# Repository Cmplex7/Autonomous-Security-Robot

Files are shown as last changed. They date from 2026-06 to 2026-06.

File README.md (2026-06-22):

# Autonomous Security Robot Platform

Autonomous security robot with real-time SLAM mapping, web dashboard control, interactive expressions, and obstacle avoidance.
Built on Raspberry Pi 4 + ROS2 Humble + STM32F103 + ESP32.

## Project Overview

* Motor Controller: STM32F103C8T6 (Blue Pill)
* Main Computer: Raspberry Pi 4 Model B (4GB) running Ubuntu Server 22.04 LTS + ROS2 Humble
* Interactive Display: ESP32 driving 2x GC9A01 Round LCDs (Robot Eyes)
* LiDAR: RPLidar A1M8 (sllidar_ros2 + slam_toolbox)
* IMU: MPU6050 GY-521
* Camera: IMX219 (Raspberry Pi Camera v2)
* Web Dashboard: rosbridge + vanilla JS

## System Architecture
```text
┌─────────────────────────────────────────────────────┐
│                Raspberry Pi 4                       │
│  ┌──────────┐  ┌──────────┐  ┌──────────────────┐   │
│  │  slam_   │  │rosbridge │  │   cam_stream.py  │   │
│  │ toolbox  │  │  :9090   │  │   (MJPEG :8080)  │   │
│  └────┬─────┘  └────┬─────┘  └──────────────────┘   │
│       │ /map        │ WebSocket                     │
│  ┌────┴──────────────────────────────────────┐      │
│  │         ROS2 Humble (CycloneDDS)          │      │
│  │  /scan_filtered  /imu/data  /cmd_vel      │      │
│  └──┬─────────────┬──────────────────────────┘      │
│     │             │                                 │
│  ┌──┴──────┐  ┌───┴─────────┐                       │
│  │RPLidar  │  │  MPU6050    │  uart_bridge.py       │
│  │ A1M8    │  │  GY-521     │  GPIO UART -> STM32   │
│  └─────────┘  └─────────────┘                       │
└─────────────────────────────────────────────────────┘
            ↕ WebSocket ws://pi-ip:9090
┌─────────────────────────────────────────────────────┐
│               Web Browser (any device)              │
│  ┌────────────────────────────────────────────────┐ │
│  │  SLAM Map · Camera Feed · Joystick · D-pad     │ │
│  │          web/index.html (served by Pi)         │ │
│  └────────────────────────────────────────────────┘ │
└─────────────────────────────────────────────────────┘
            ↕ UART (115200 baud, GPIO14/15)
┌─────────────────────────────────────────────────────┐
│                STM32F103C8T6                        │
│  Motor PWM · HC-SR04 Ultrasonic · AUTO navigation   │
└─────────────────────────────────────────────────────┘
┌─────────────────────────────────────────────────────┐
│                ESP32 (Expression Module)            │
│  SPI Bus -> 2x GC9A01 Round LCDs (Interactive Eyes) │
└─────────────────────────────────────────────────────┘
```
## Repository Structure

* /docs: Setup guides, wiring diagrams, and motor shield datasheets.
* /hardware: 3D printed mechanical parts and KiCAD PCB schematics.
* /stm32: Low-level STM32 firmware for motor control and obstacle avoidance.
* /esp32: Firmware for LCD eyes rendering and animation control.
* /raspberry_pi: ROS2 workspace containing custom nodes for IMU processing and UART bridging.
* /web: Web dashboard interface and MJPEG camera streaming script.

## Hardware Integration & Wiring

ESP32 to GC9A01 Round LCDs (SPI)
* MOSI / SCLK: Shared SPI data and clock lines for both screens.
* CS1 / CS2: Independent Chip Select pins to control Left and Right eyes.
* DC / RST: Data/Command and Reset pins.

STM32 to Motor Driver (L298N / TB6612)
* PA0 (ENA) / PA1 (ENB): Motor PWM
* PA2 / PA3: Left motor direction
* PA4 / PA5: Right motor direction

Pi 4 to STM32 (UART)
* GPIO14 (TX, pin 8) -> RX (PA10 / Serial1)
* GPIO15 (RX, pin 10) -> TX (PA9 / Serial1)

Please refer to the /docs directory for complete wiring diagrams and system setup instructions.

## Quick Start

1. Clone the repository:
   git clone https://github.com/Cmplex7/Autonomous-Security-Robot.git

2. Flash STM32 Firmware: Open `stm32/robot_final.ino` in Arduino IDE with the STM32duino board package. Upload via Serial or ST-Link at 115200 baud.

3. Flash ESP32 Firmware: Upload the GC9A01 display code to the ESP32 module to initialize the screen animations.

4. Set Up Raspberry Pi 4: Follow the detailed setup guide in the `docs/` folder to install Ubuntu Server 22.04 LTS and ROS2 Humble.

5. Launch Workspace: Compile the ROS2 packages using `colcon build` and launch the bringup scripts.

## STM32 UART Command Protocol

Commands are sent as ASCII strings terminated with \n at 115200 baud:
* ON / BACK / LEFT / RIGHT: Basic directional movement
* UP_LEFT / UP_RIGHT / DOWN_LEFT / DOWN_RIGHT: Arced movement
* AUTO: Enable onboard ultrasonic obstacle avoidance
* OFF / MANUAL: Stop and exit AUTO mode

## Author
ThanhDat (CmpleX7)

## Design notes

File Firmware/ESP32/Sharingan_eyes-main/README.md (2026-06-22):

# Sharingan Eyes 👁️👁️

Mắt hoạt hình (animated eyes) trên ESP32 với **lõi mắt thay được lúc chạy** bằng nút bấm:
mắt người → Sharingan tomoe → Mangekyou Kamui (Obito) → Mangekyou vĩnh hằng (Sasuke) → Rinnegan.

Mắt tự đảo tròng, chớp mắt, mí mắt bám theo con ngươi — dựa trên engine
"Uncanny Eyes" của Adafruit, bản port TFT_eSPI cho ESP32.

## Phần cứng

- ESP32 DevKit V1 (loại thông dụng, chip CH340)
- 2 × LCD tròn 1.28" GC9A01, 240×240 (chân BLK, CS, DC, RES, SDA, SCL, VCC, GND)
- 1 nút bấm (đổi lõi mắt)

### Sơ đồ đấu dây

| Chân màn hình | Màn TRÁI | Màn PHẢI | Ghi chú |
|---|---|---|---|
| VCC | 3V3 | 3V3 | ⚠️ Không cắm 5V, không đảo ngược VCC/GND |
| GND | GND | GND | |
| SCL | GPIO 18 | GPIO 18 | SPI clock, dùng chung |
| SDA | GPIO 23 | GPIO 23 | SPI MOSI, dùng chung |
| DC | GPIO 22 | GPIO 22 | Dùng chung |
| RES | GPIO 4 | GPIO 4 | Dùng chung |
| CS | GPIO 5 | GPIO 21 | Mỗi màn một chân riêng |
| BLK | 3V3 | 3V3 | Đèn nền luôn bật |

Nút bấm: một chân **GPIO 27**, chân kia **GND** (dùng pull-up nội, không cần điện trở).

## Build & nạp (PlatformIO)

```bash
pio run -t upload
```

Cổng COM và toàn bộ cấu hình chân TFT_eSPI nằm trong `platformio.ini` (build_flags),
không cần sửa `User_Setup.h` của thư viện. Cấu hình mắt trong `include/config.h`.

## Đổi lõi mắt

Nhấn nút GPIO27: xoay vòng qua 5 lõi. Mỗi lần đổi, firmware in `Doi loi mat -> ...`
ra Serial (115200). Lõi khởi động mặc định đặt trong `main.cpp` (`irisStyleIndex`).

## Tự tạo lõi mắt mới

Engine không nhận ảnh tròn trực tiếp — iris là texture 256×64 "trải" theo tọa độ cực
(cột = góc 0–360°, hàng = bán kính từ mép vào tâm). Dùng script kèm theo:

```bash
python tools/make_iris.py anh_tron.png iris_ten_moi iris_ten_moi.h [cx cy r]
```

Script xuất kèm ảnh `_preview.png` (tái dựng hình tròn) để soát trước khi nạp.
Sau đó: copy file `.h` vào `src/eyes/`, thêm `#include` trong `include/config.h`,
và thêm một dòng vào bảng `irisStyles[]` trong `src/main.cpp` với scale `121, 121`.

> **Lưu ý kỹ thuật:** lõi "phẳng" (texture phủ kín cả vòng iris) phải dùng
> `iScale = 121`, không phải 120. Pixel ngoài vòng tròn iris mang mã polar
> `dist = 127`; cần `121×127/240 = 64 ≥ IRIS_MAP_HEIGHT` để chúng rơi ra lòng
> trắng — với 120 chúng rơi vào hàng 63 của texture và iris sẽ bị **vuông**.
> Lõi mắt người mặc định dùng `IRIS_MIN/IRIS_MAX` (180–280) nên có hiệu ứng
> giãn/co đồng tử; lõi Sharingan cố định đồng tử.

Preview các lõi có sẵn (sinh bởi `make_iris.py`):

| Tomoe | Kamui | Sasuke | Rinnegan |
|---|---|---|---|
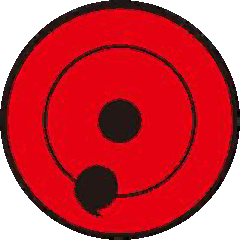
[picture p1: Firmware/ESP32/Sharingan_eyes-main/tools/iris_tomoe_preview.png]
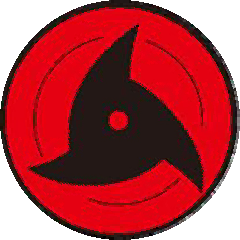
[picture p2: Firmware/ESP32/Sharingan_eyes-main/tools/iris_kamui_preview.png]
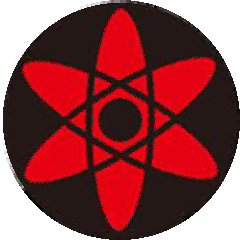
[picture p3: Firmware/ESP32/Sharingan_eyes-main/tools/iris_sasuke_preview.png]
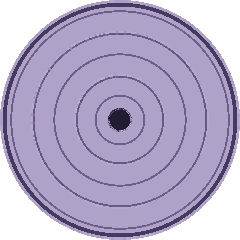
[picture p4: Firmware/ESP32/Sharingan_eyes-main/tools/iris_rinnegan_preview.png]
|  |  |  |  |

## Ghi công

- Engine gốc: [Uncanny Eyes](https://github.com/adafruit/Uncanny_Eyes) — Phil Burgess / Adafruit
- Port TFT_eSPI + ESP32: dự án ESP32-UncannyEyes (PlatformIO, xem `readme_goc.md`) và các ví dụ Animated Eyes của [Bodmer/TFT_eSPI](https://github.com/Bodmer/TFT_eSPI)
- Lõi Sharingan/Rinnegan + nút đổi lõi lúc chạy + script `make_iris.py`: repo này

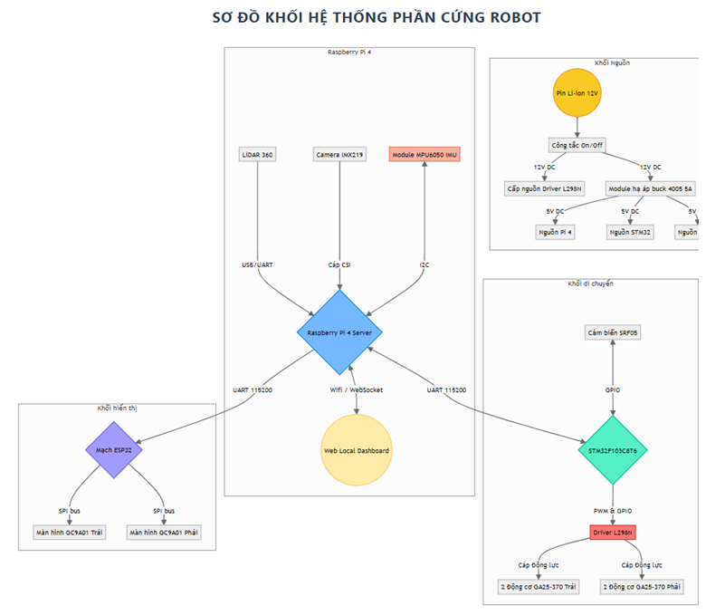
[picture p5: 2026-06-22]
Docs/Robot_System_Diagram.png

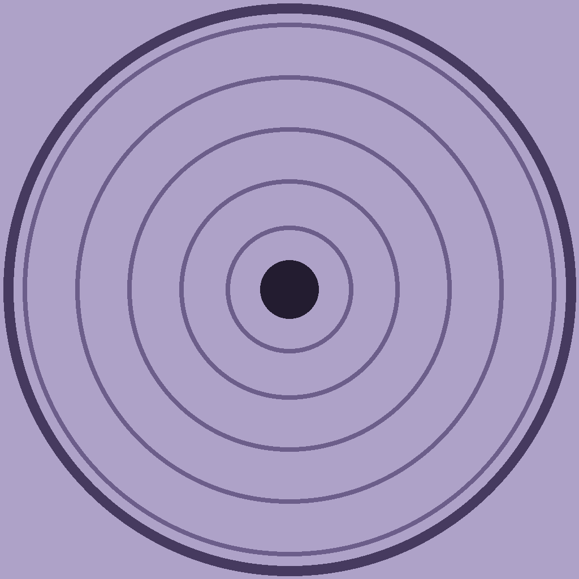
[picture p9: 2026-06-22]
Firmware/ESP32/Sharingan_eyes-main/tools/rinnegan_src.png

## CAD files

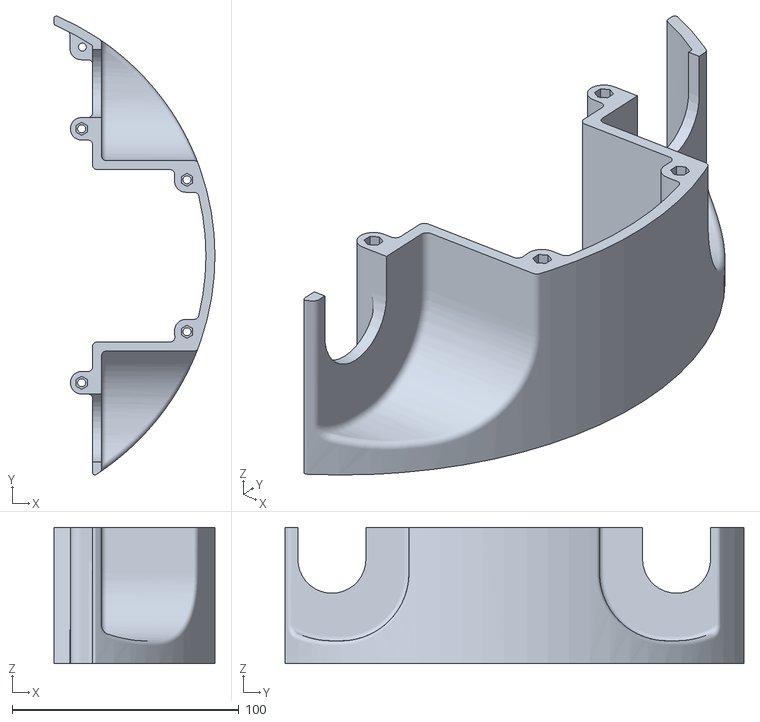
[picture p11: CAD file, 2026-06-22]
System Design/Security Robot Design/tấm 1.STL
71.0 x 202.4 x 60.0

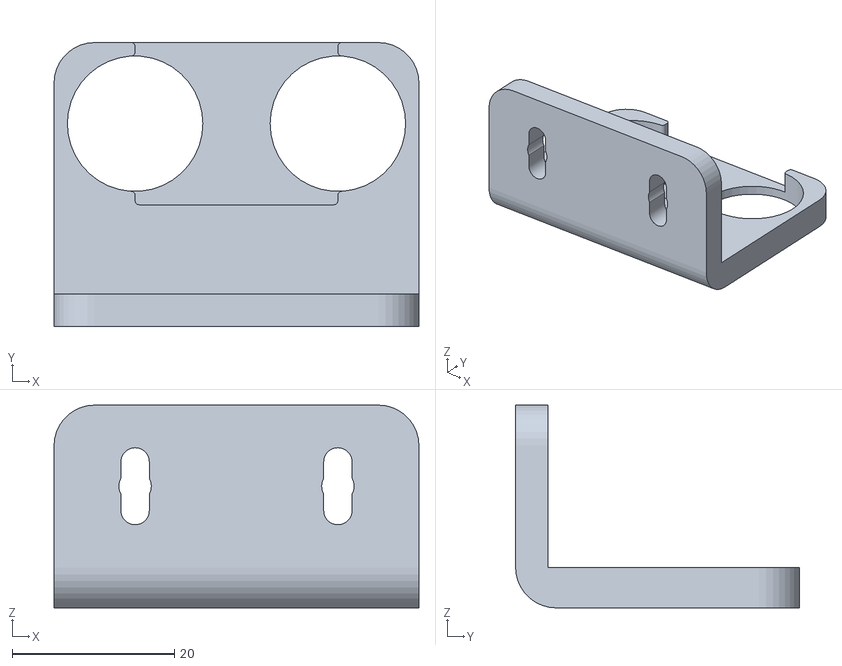
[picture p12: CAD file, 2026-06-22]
System Design/Security Robot Design/4x kẹp cảm biến siêu âm.STL
45.0 x 35.0 x 25.0

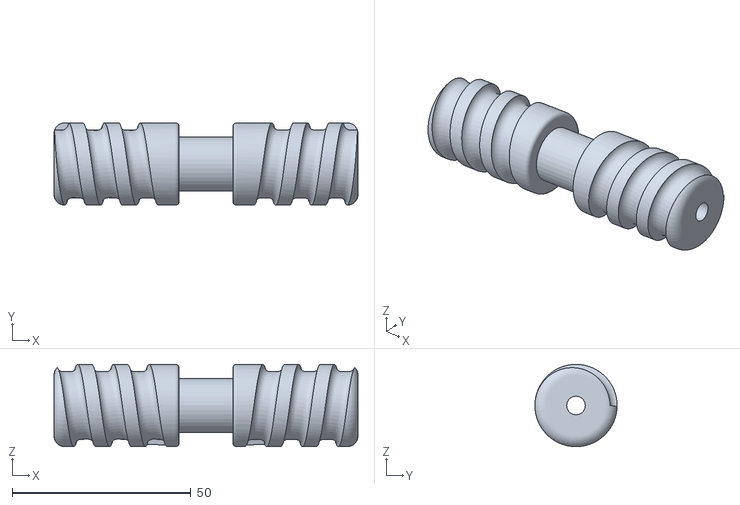
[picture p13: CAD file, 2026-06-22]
System Design/Security Robot Design/1x con lăn định tâm.STL
85.0 x 23.0 x 23.0

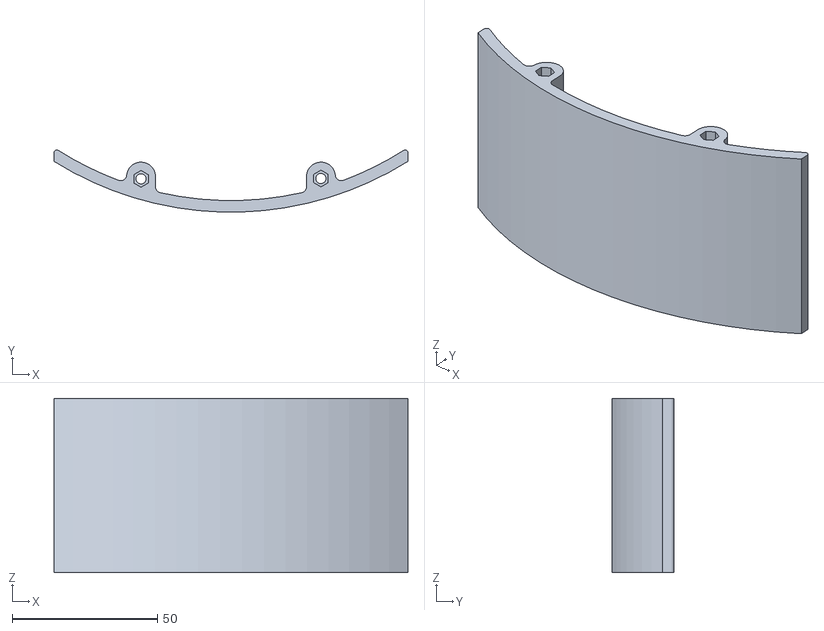
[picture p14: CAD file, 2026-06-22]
System Design/Security Robot Design/tấm 3.STL
122.0 x 21.4 x 60.0

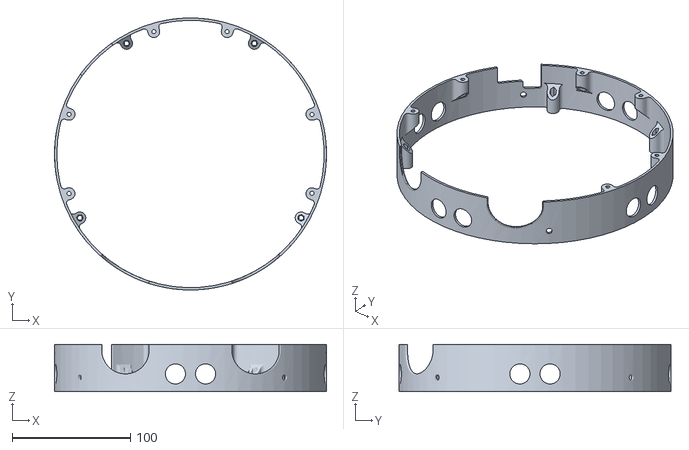
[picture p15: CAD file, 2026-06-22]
System Design/Security Robot Design/1x tang 2.STL
230.0 x 229.8 x 40.0

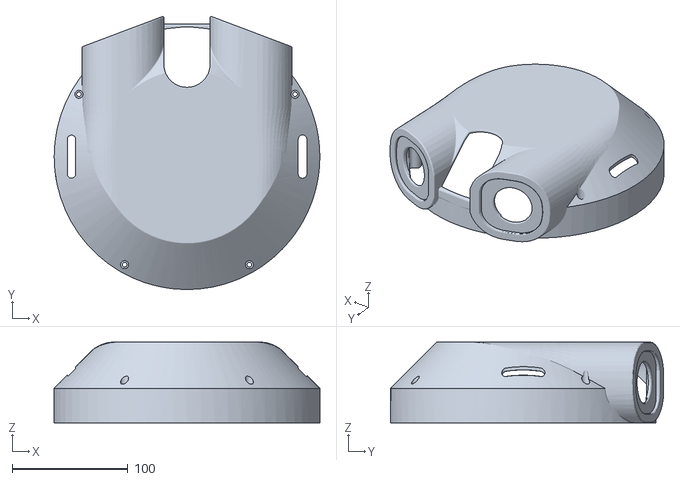
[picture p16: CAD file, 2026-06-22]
System Design/Security Robot Design/1x tang 3.STL
230.0 x 236.3 x 70.0

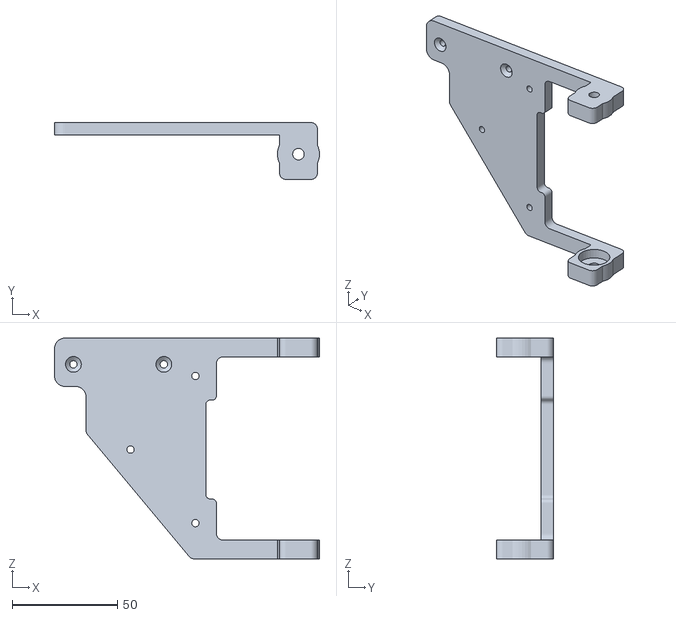
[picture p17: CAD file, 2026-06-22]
System Design/Security Robot Design/1x đỡ định tâm bóng.STL
126.0 x 27.0 x 105.0

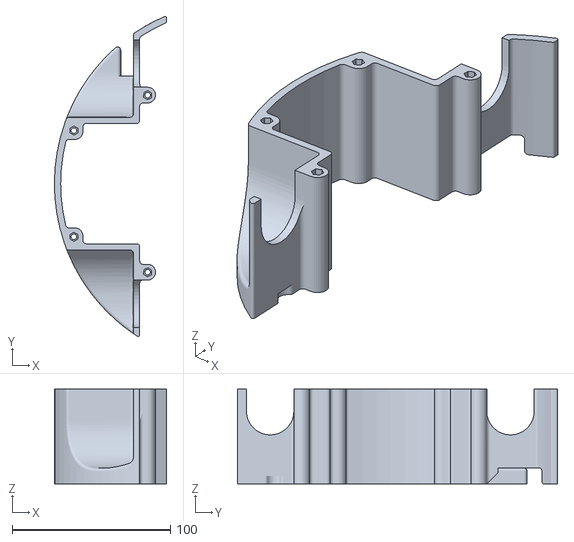
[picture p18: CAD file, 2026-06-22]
System Design/Security Robot Design/1x tấm 2.STL
71.0 x 202.4 x 60.0

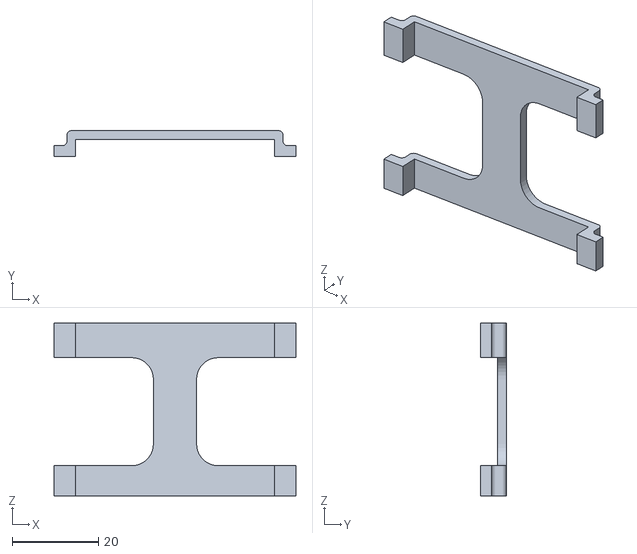
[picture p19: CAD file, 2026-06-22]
System Design/Security Robot Design/2x nẹp.STL
56.0 x 5.96 x 40.0

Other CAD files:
System Design/Security Robot Design/01_mica.DXF
System Design/Security Robot Design/00_mica.DXF
System Design/Security Robot Design/02_mica.DXF

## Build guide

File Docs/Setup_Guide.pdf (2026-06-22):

# Cài trên Pi

## 1.1. Pi4 model B + RPLidar A1M8 - Cài đặt Ubuntu Server 22 LTS (64-bit) + Hostname: robotanninh + Username/ Password: ubuntu/ abc123 + Kết nối Lidar và Pi4b qua USB - USB micro B, cổng đen

## - Cập nhật hệ điều hành:

sudo apt update && sudo apt upgrade -y sudo reboot

## - Tạo file swap 4GB ram ảo:

sudo fallocate -l 4G /swapfile
sudo chmod 600 /swapfile
sudo mkswap /swapfile
sudo swapon /swapfile
echo '/swapfile none swap sw 0 0' | sudo tee -a /etc/fstab

## - Thiết lập ngôn ngữ:

sudo apt install -y software-properties-common curl locales
sudo locale-gen en_US en_US.UTF-8
sudo update-locale LC_ALL=en_US.UTF-8 LANG=en_US.UTF-8 export LANG=en_US.UTF-8

## - Kích hoạt kho Universe:

sudo add-apt-repository universe -y

## 1.2. Thêm ROS2 Humble repository:

sudo apt install -y curl
export ROS_APT_SOURCE_VERSION=$(curl -s \ https://api.github.com/repos/ros-infrastructure/ros-apt-source/releases/latest \
| grep -F '"tag_name"' | awk -F\" '{print $4}')
echo "ros-apt-source version: $ROS_APT_SOURCE_VERSION"

curl -L -o /tmp/ros2-apt-source.deb \

"https://github.com/ros-infrastructure/ros-apt-source/releases/download/${ROS_APT_SOURCE_VERSION}/ros2-apt-source_${ROS_APT_SOURCE_VERSION}.$(. /etc/os-release && echo $VERSION_CODENAME)_all.deb"
sudo dpkg -i /tmp/ros2-apt-source.deb

## - Cài ROS2 Humble:

sudo apt update
sudo apt install -y ros-humble-ros-base ros-dev-tools

## - Cài packages mở rộng (SLAM, Web, DDS):

sudo apt install -y \
ros-humble-slam-toolbox \
ros-humble-rosbridge-suite \
ros-humble-rmw-cyclonedds-cpp

## - Cấu hình môi trường:

echo 'source /opt/ros/humble/setup.bash' >> ~/.bashrc
echo 'export RMW_IMPLEMENTATION=rmw_cyclonedds_cpp' >> ~/.bashrc echo 'export ROS_DOMAIN_ID=42' >> ~/.bashrc
source ~/.bashrc

## - Cài bộ đồng bộ thời gian:

sudo apt update && sudo apt install chrony -y

## 1.3. Tạo Workspace & Tải mã nguồn của RPLidar A1M8::

mkdir -p ~/ros2_ws/src
cd ~/ros2_ws/src
git clone https://github.com/Slamtec/sllidar_ros2.git

## 1.4. Cấu hình lidar:

sudo usermod -aG dialout ubuntu
sudo systemctl disable --now ModemManager

## - Udev rule cố định /dev/rplidar: sudo nano /etc/udev/rules.d/99-rplidar.rules

KERNEL=="ttyUSB*", ATTRS{idVendor}=="10c4", ATTRS{idProduct}=="ea60", MODE="0666", GROUP="dialout", SYMLINK+="rplidar"

sudo udevadm control --reload-rules && sudo udevadm trigger

## 1.5 Cấu Hình I2C + MPU6050 GY-521: - Kích hoạt I2C trong config.txt: sudo nano /boot/firmware/config.txt

dtparam=i2c_arm_baudrate=400000

## - Nạp module i2c-dev khi boot:

echo 'i2c-dev' | sudo tee /etc/modules-load.d/i2c.conf

## - Cài công cụ & thư viện:

sudo apt install -y i2c-tools python3-pip
pip3 install smbus2

## - Phân quyền I2C cho user ubuntu:

sudo groupadd -f i2c
sudo usermod -aG i2c ubuntu
echo 'KERNEL=="i2c-[0-9]*", GROUP="i2c", MODE="0660"' \ | sudo tee /etc/udev/rules.d/99-i2c.rules
sudo udevadm control --reload-rules && sudo udevadm trigger

## 1.6. Tạo Package web_pose

cd ~/ros2_ws/src
ros2 pkg create web_pose \
--build-type ament_python \
--dependencies rclpy geometry_msgs tf2_ros tf2_geometry_msgs nav_msgs sensor_msgs \ --license Apache-2.0

mkdir -p ~/ros2_ws/src/web_pose/launch
mkdir -p ~/ros2_ws/config

## 1.8. Các chức năng về scan

sudo apt update
sudo apt install ros-humble-laser-filters -y

## - Tạo cấu hình scan: nano ~/ros2_ws/config/laser_filter.yaml

scan_to_scan_filter_chain:
ros__parameters:
filter1:
name: range_filter
type: laser_filters/LaserScanRangeFilter params:
use_message_range_limits: false lower_threshold: 0.15
upper_threshold: 12.0
lower_replacement_value: .inf upper_replacement_value: .inf

## 1.9. Tạo file đọc IMU: nano ~/ros2_ws/src/web_pose/web_pose/mpu6050_driver.py

#!/usr/bin/env python3

import rclpy
from rclpy.node import Node
from sensor_msgs.msg import Imu import smbus2
import math
import time

MPU6050_ADDR = 0x68
PWR_MGMT_1 = 0x6B
GYRO_CONFIG = 0x1B
GYRO_XOUT_H = 0x43

GYRO_SCALE = 131.0
DEG2RAD = math.pi / 180.0
SCALE_FACTOR = DEG2RAD / GYRO_SCALE CALIBRATE_N = 150

class MPU6050Driver(Node):
def __init__(self):
super().__init__('mpu6050_driver')
self.bus = smbus2.SMBus(1) self.bus.write_byte_data(MPU6050_ADDR, PWR_MGMT_1, 0x00) time.sleep(0.1)
self.bus.write_byte_data(MPU6050_ADDR, GYRO_CONFIG, 0x00) time.sleep(0.05)
self._gz_offset = self._calibrate()
self.pub = self.create_publisher(Imu, '/imu/data', 10)
self.create_timer(0.02, self._publish)
self.get_logger().info(f'MPU6050 ready: offset={math.degrees(self._gz_offset):.3f} deg/s')

def _read_i16(self, reg: int) -> int:
d = self.bus.read_i2c_block_data(MPU6050_ADDR, reg, 2)
v = (d[0] << 8) | d[1]
return v - 65536 if v >= 0x8000 else v

def _calibrate(self) -> float:
total = 0.0
for _ in range(CALIBRATE_N):
total += self._read_i16(GYRO_XOUT_H + 4) time.sleep(0.02)
return (total / CALIBRATE_N) * SCALE_FACTOR

def _publish(self):
try:
d = self.bus.read_i2c_block_data(MPU6050_ADDR, GYRO_XOUT_H, 6)
v = (d[4] << 8) | d[5]
gz_raw = v - 65536 if v >= 0x8000 else v
gz_rads = (gz_raw * SCALE_FACTOR) - self._gz_offset

msg = Imu()
msg.header.stamp = self.get_clock().now().to_msg() msg.header.frame_id = 'imu_link' msg.angular_velocity.z = float(gz_rads) msg.angular_velocity_covariance = [
1e6, 0.0, 0.0,
0.0, 1e6, 0.0,
0.0, 0.0, 1e-4
]
msg.linear_acceleration_covariance[0] = -1.0 msg.orientation_covariance[0] = -1.0
self.pub.publish(msg)
except Exception as e:
self.get_logger().warn(f'IMU Error: {e}', throttle_duration_sec=3.0)

def main():

rclpy.init()
node = MPU6050Driver()
try:
rclpy.spin(node)
except KeyboardInterrupt:
pass
finally:
node.destroy_node()
rclpy.shutdown()

if __name__ == '__main__': main()

## 1.10. Tạo file giao tiếp STM32: nano ~/ros2_ws/src/web_pose/web_pose/uart_bridge.py

#!/usr/bin/env python3

import rclpy
from rclpy.node import Node
from rclpy.qos import QoSProfile, ReliabilityPolicy, HistoryPolicy from geometry_msgs.msg import Twist
from std_msgs.msg import String
import serial
import time

LIN_THRESH = 0.05
ANG_THRESH = 0.15
SERIAL_PORT = '/dev/ttyAMA0'
BAUD = 115200

def twist_to_cmd(lx: float, az: float) -> str: fwd = lx > LIN_THRESH
back = lx < -LIN_THRESH
lft = az > ANG_THRESH
rgt = az < -ANG_THRESH

if fwd and lft: return 'UP_LEFT'
if fwd and rgt: return 'UP_RIGHT'
if fwd: return 'ON'
if back and lft: return 'DOWN_LEFT' if back and rgt: return 'DOWN_RIGHT' if back: return 'BACK'
if lft: return 'LEFT'
if rgt: return 'RIGHT'
return 'OFF'

class UartBridge(Node):
def __init__(self):
super().__init__('uart_bridge') self._last_cmd = ''
self._auto_mode = False
self.ser = None
self._open_serial(initial=True)
self._reconnect_timer = self.create_timer(2.0, self._check_serial)

qos = QoSProfile(
reliability=ReliabilityPolicy.RELIABLE, history=HistoryPolicy.KEEP_LAST,
depth=1
)
self.create_subscription(Twist, '/cmd_vel', self._on_vel, qos) self.create_subscription(String, '/robot_mode', self._on_mode, 10)

def _open_serial(self, initial: bool = False) -> bool:
try:
self.ser = serial.Serial(SERIAL_PORT, BAUD, timeout=1) time.sleep(2.0 if initial else 0.2)
self._last_cmd = ''
return True
except Exception as e:
self.ser = None
self.get_logger().warn(f'Serial Error: {e}') return False

def _check_serial(self):
if self.ser is None or not self.ser.is_open: self._open_serial(initial=False)

def _write(self, cmd: str):
if cmd == self._last_cmd:
return
if self.ser is None or not self.ser.is_open:

return
try:
self.ser.write(f'{cmd}\n'.encode('utf-8')) self.ser.flush()
self._last_cmd = cmd
except Exception as e:
self.get_logger().error(f'Write error: {e}') try:
self.ser.close()
except Exception:
pass
self.ser = None

def _on_vel(self, msg: Twist):
if self._auto_mode:
return
self._write(twist_to_cmd(msg.linear.x, msg.angular.z))

def _on_mode(self, msg: String):
mode = msg.data.strip().upper()
if mode == 'AUTO':
self._auto_mode = True
self._write('AUTO')
else:
self._auto_mode = False
self._write('OFF')

def stop_robot(self):
if self.ser and self.ser.is_open: try:
self.ser.write(b'OFF\n')
self.ser.flush()
except Exception:
pass

def main(args=None):
rclpy.init(args=args)
node = UartBridge()
try:
rclpy.spin(node)
except KeyboardInterrupt:
pass
finally:
node.stop_robot()
if node.ser and node.ser.is_open: node.ser.close()
node.destroy_node()
if rclpy.ok():
rclpy.shutdown()

if __name__ == '__main__':
main()

## - Điều khiển phần cứng: nano ~/ros2_ws/src/web_pose/launch/robot_bringup.launch.py

import os
from launch import LaunchDescription
from launch_ros.actions import Node

def generate_launch_description():
# Construct the absolute path to the C++ filter config file filter_config = os.path.join(

os.path.expanduser('~'), 'ros2_ws', 'config', 'laser_filter.yaml' )

return LaunchDescription([
# 1. LiDAR Driver Node

Node(
package='sllidar_ros2',
executable='sllidar_node', name='sllidar_node',
parameters=[{
'serial_port': '/dev/rplidar', 'serial_baudrate': 115200, 'frame_id': 'laser',
'scan_mode': 'Standard'
}],
output='screen'
),

# 2. C++ Laser Scan Filter Node (Cuts off noise < 15cm) Node(

package='laser_filters', executable='scan_to_scan_filter_chain', name='laser_filter',
parameters=[filter_config],
remappings=[
('scan', '/scan'),
('scan_filtered', '/scan_filtered') ],
output='screen'
),

# 3. Static Transform: base_link -> laser (LiDAR height: 0.23m) Node(

package='tf2_ros',
executable='static_transform_publisher',
arguments=[
'--x', '0.0', '--y', '0.0', '--z', '0.23',
'--yaw', '0', '--pitch', '0', '--roll', '0',
'--frame-id', 'base_link', '--child-frame-id', 'laser' ],
output='screen'
),

# 4. Static Transform: base_link -> imu_link (IMU height: 0.09m) Node(

package='tf2_ros',
executable='static_transform_publisher',
arguments=[
'--x', '0.0', '--y', '0.0', '--z', '0.09',
'--yaw', '0', '--pitch', '0', '--roll', '0',
'--frame-id', 'base_link', '--child-frame-id', 'imu_link' ],
output='screen'
),

# 5. MPU6050 IMU Driver Node Node(

package='web_pose',
executable='mpu6050_driver', name='mpu6050_driver',
output='screen'
),

# 6. STM32 UART Bridge Node Node(

package='web_pose',
executable='uart_bridge',
name='uart_bridge',
output='screen'
)
])

## - Bổ sung config: nano ~/ros2_ws/src/web_pose/setup.py

from setuptools import find_packages, setup
import os
from glob import glob

package_name = 'web_pose'

setup(
name=package_name,
version='0.0.0',
packages=find_packages(exclude=['test']), data_files=[
('share/ament_index/resource_index/packages',
['resource/' + package_name]),
('share/' + package_name, ['package.xml']), (os.path.join('share', package_name, 'launch'), glob('launch/*.py')), ],
install_requires=['setuptools'],
zip_safe=True,
maintainer='ubuntu',
maintainer_email='ubuntu@todo.todo', description='Web pose package', license='Apache-2.0',
extras_require={
'test': [
'pytest',
],
},
entry_points={
'console_scripts': [
'mpu6050_driver = web_pose.mpu6050_driver:main',

'uart_bridge = web_pose.uart_bridge:main', ],
},
)

## 1.11. Build pakage:

cd ~/ros2_ws && colcon build --packages-select web_pose --symlink-install && source ~/.bashrc
ros2 pkg list | grep web_pose

## 1.12. CycloneDDS Cross-Machine (Pi ↔ Ubuntu VM)

sudo apt update
sudo apt install -y avahi-daemon
sudo systemctl enable --now avahi-daemon

cat > ~/cyclone_dds.xml << 'EOF'
<?xml version="1.0" encoding="utf-8"?> <CycloneDDS>
<Domain>
<General>
<NetworkInterfaceAddress>auto</NetworkInterfaceAddress> </General>
<Discovery>
<Peers>
<Peer address="vmuser-virtual-machine.local"/> </Peers>
</Discovery>
</Domain>
</CycloneDDS>
EOF

echo 'export CYCLONEDDS_URI=file:///home/ubuntu/cyclone_dds.xml' >> ~/.bashrc source ~/.bashrc

## 2.1. Cấu hình phần cứng camera IMX219:

sudo sed -i '/camera_auto_detect/d' /boot/firmware/config.txt
sudo sed -i '/dtoverlay=imx219/d' /boot/firmware/config.txt
echo "dtoverlay=imx219" | sudo tee -a /boot/firmware/config.txt
sudo sed -i -e 's/ cma=[^ ]*//g' -e '1s/$/ cma=128M/' /boot/firmware/cmdline.txt

## 2.2. Udev DMA Heap:

echo 'SUBSYSTEM=="dma_heap", GROUP="video", MODE="0666"' \ | sudo tee /etc/udev/rules.d/99-dma-heap.rules

sudo tee /etc/systemd/system/dma-heap-cma.service << 'EOF' [Unit]
Description=Create dma_heap linux,cma symlink for rpicam-apps After=local-fs.target
[Service]
Type=oneshot
ExecStart=/bin/ln -sf /dev/dma_heap/reserved /dev/dma_heap/linux,cma RemainAfterExit=yes
[Install]
WantedBy=multi-user.target
EOF

sudo systemctl daemon-reload
sudo systemctl enable dma-heap-cma.service

## 2.3. Build libcamera & rpicam-apps:

sudo apt update
sudo apt install -y \
clang meson ninja-build pkg-config cmake \
libyaml-dev python3-yaml python3-ply python3-jinja2 openssl \ libdw-dev libunwind-dev libudev-dev \
libgstreamer1.0-dev libgstreamer-plugins-base1.0-dev \ libpython3-dev pybind11-dev libevent-dev libtiff-dev \ liblttng-ust-dev lttng-tools libgtest-dev \
libboost-dev libboost-program-options-dev \ libdrm-dev libexif-dev libjpeg-dev libpng-dev

sudo pip3 install --upgrade meson

# libcamera

cd ~
git clone https://github.com/raspberrypi/libcamera.git cd libcamera
meson setup build --buildtype=release \ -Dpipelines=rpi/vc4,rpi/pisp \ -Dipas=rpi/vc4,rpi/pisp \
-Dv4l2=true \
-Dgstreamer=enabled \
-Dtest=false \
-Dlc-compliance=disabled \ -Dcam=disabled \
-Dqcam=disabled \
-Ddocumentation=disabled \ -Dpycamera=enabled
ninja -C build -j2
sudo ninja -C build install sudo ldconfig

# rpicam-apps

cd ~
git clone https://github.com/raspberrypi/rpicam-apps.git cd rpicam-apps
meson setup build \
-Denable_libav=disabled \
-Denable_drm=disabled \
-Denable_egl=disabled \
-Denable_qt=disabled \
-Denable_opencv=disabled \ -Denable_tflite=disabled \ -Denable_hailo=disabled
meson compile -C build -j2
sudo meson install -C build
sudo ldconfig

sudo usermod -aG video,render ubuntu

## 2.4. Tạo luồng stream camera: mkdir -p ~/web nano ~/web/cam_stream.py

#!/usr/bin/env python3

"""
MJPEG Streaming Server using rpicam-vid.
Runs independently of ROS 2, optimized for low latency and memory safety. """
import subprocess
import threading
import time
from http.server import BaseHTTPRequestHandler, ThreadingHTTPServer

WIDTH, HEIGHT, FPS = 640, 480, 30
BOUNDARY = b'jpgboundary'
PORT = 8080
MAX_BUF_SIZE = 1048576 # 1MB limit to prevent memory leak

class CamStream:
def __init__(self):
self.frame = b''
self.condition = threading.Condition() self.proc = self._start_rpicam()

threading.Thread(target=self._read_frames, daemon=True).start() print(f'[CAM] rpicam-vid started at {WIDTH}x{HEIGHT}@{FPS}fps')

def _start_rpicam(self):
"""Helper method to start or restart the rpicam-vid process.""" return subprocess.Popen([
'rpicam-vid', '-t', '0',
'--width', str(WIDTH), '--height', str(HEIGHT), '--framerate', str(FPS),
'--codec', 'mjpeg', '--nopreview', '-o', '-'
], stdout=subprocess.PIPE, stderr=subprocess.DEVNULL)

def _read_frames(self):
buf = b''
while True:
chunk = self.proc.stdout.read(4096) if not chunk:
self._restart()
buf = b''
continue

buf += chunk

# Memory leak protection: clear buffer if it grows too large

if len(buf) > MAX_BUF_SIZE:
print('[CAM] Warning: Buffer overflow detected. Flushing buffer.') buf = b''
continue

while True:
start = buf.find(b'\xff\xd8')
if start == -1:
break
end = buf.find(b'\xff\xd9', start + 2) if end == -1:
break

# Extract the complete JPEG frame with self.condition:

self.frame = buf[start:end+2] self.condition.notify_all()

# Truncate buffer to process next frame

buf = buf[end+2:]

def _restart(self):
print('[CAM] rpicam-vid crashed, restarting in 2s...') try:
self.proc.kill()
except Exception:
pass
time.sleep(2)
self.proc = self._start_rpicam()
print('[CAM] rpicam-vid restarted successfully')

def get_frame(self):
with self.condition:
# Wait up to 1 second for a new frame self.condition.wait(timeout=1.0) return self.frame

cam = CamStream()

class StreamHandler(BaseHTTPRequestHandler): def do_GET(self):
if self.path.split('?')[0] == '/stream.mjpg':
self.send_response(200)
self.send_header('Content-Type', f'multipart/x-mixed-replace; boundary={BOUNDARY.decode()}') self.send_header('Access-Control-Allow-Origin', '*')
self.end_headers()
try:
while True:
frame = cam.get_frame()
if frame:
self.wfile.write(b'--' + BOUNDARY + b'\r\n') self.wfile.write(b'Content-Type: image/jpeg\r\n\r\n') self.wfile.write(frame)
self.wfile.write(b'\r\n')
except Exception:
# Client disconnected

pass
else:
self.send_error(404)

def log_message(self, *args):

# Disable default logging to keep terminal output clean

pass

if __name__ == '__main__':
print(f'[CAM] MJPEG server is running: http://0.0.0.0:{PORT}/stream.mjpg') try:
ThreadingHTTPServer(('', PORT), StreamHandler).serve_forever() except KeyboardInterrupt:
print("\n[CAM] Shutting down...")
try:
cam.proc.kill()
except Exception:
pass

## 3.1. Kết hợp pi và stm32 qua uart gpio:

sudo nano /boot/firmware/config.txt

dtoverlay=disable-bt

## - Vô hiệu hóa service chiếm quyền UART:

sudo systemctl mask serial-getty@ttyAMA0.service

- Kiểm tra thêm cmdline.txt: nếu file /boot/firmware/cmdline.txt có chuỗi console=serial0,115200, kernel sẽ đổ log boot ra chính UART nối STM32 → STM32 có thể nhận nhiễu lúc khởi động. Gỡ bỏ nó:

sudo sed -i 's/console=serial0,[0-9]* //' /boot/firmware/cmdline.txt

## 3.2. Mở cổng UFW

sudo ufw allow 8000 # web dashboard sudo ufw allow 8080 # camera MJPEG sudo ufw reload

## - Rebuild:

cd ~/ros2_ws
rosdep install --from-paths src --ignore-src -r -y
colcon build --packages-select web_pose sllidar_ros2 --symlink-install source ~/.bashrc
source ~/ros2_ws/install/setup.bash

sudo reboot

## 4. Web dashboard:

cd ~/web
curl -L -o roslib.min.js "https://cdn.jsdelivr.net/npm/roslib@1.3.0/build/roslib.min.js" nano ~/web/index.html

<!DOCTYPE html>
<html lang="en">
<head>
<meta charset="UTF-8">
<meta name="viewport" content="width=device-width, initial-scale=1.0"> <title>Robot An Ninh — SLAM Dashboard</title>
<link rel="preconnect" href="https://fonts.googleapis.com">

<link href="https://fonts.googleapis.com/css2?family=Share+Tech+Mono&family=Exo+2:wght@300;400;600;700&display=swap"rel="stylesheet">
<script src="/roslib.min.js"></script>
<style>
:root {
--bg:#080c10; --surface:#0d1117; --panel:#111820; --border:#1e2d3d; --accent:#00d4ff; --accent2:#00ff88; --danger:#e94560; --text:#c9d1d9; --muted:#4a5568;
--mono:'Share Tech Mono',monospace; --body:'Exo 2',sans-serif;
}
*{box-sizing:border-box;margin:0;padding:0;} body{background:var(--bg);color:var(--text);font-family:var(--body);height:100vh;display:flex;flex-direction:column;overflow:hidden;} body::before{content:'';position:fixed;inset:0;background:repeating-linear-gradient(0deg,transparent,transparent 2px,rgba(0,212,255,0.012) 2px,rgba(0,212,255,0.012) 4px);pointer-events:none;z-index:1000;}

/* ── Header ── */
header{background:var(--surface);padding:0 14px;height:44px;display:flex;align-items:center;gap:10px;border-bottom:1px solid var(--border);flex-shrink:0;position:relative;}

header::after{content:'';position:absolute;bottom:0;left:0;right:0;height:1px;background:linear-gradient(90deg,transparent,var(--accent),transpar ent);opacity:.4;}
.status-dot{width:8px;height:8px;border-radius:50%;background:var(--danger);flex-shrink:0;transition:background .4s;} .status-dot.ok{background:var(--accent2);animation:pulse-green 2s infinite;}
@keyframes pulse-green{0%{box-shadow:0 0 0 0 rgba(0,255,136,.6)}70%{box-shadow:0 0 0 6px rgba(0,255,136,0)}100%{box-shadow:0 0 0 0 rgba(0,255,136,0)}}
.logo{font-family:var(--mono);font-size:13px;color:var(--accent);letter-spacing:2px;text-transform:uppercase;}
.logo span{color:var(--danger);}
#conn-status{font-family:var(--mono);font-size:10px;color:var(--muted);letter-spacing:1px;} .header-right{margin-left:auto;display:flex;align-items:center;gap:12px;} .header-time{font-family:var(--mono);font-size:11px;color:var(--accent);opacity:.7;}

/* ── Main layout ── */
main{flex:1;display:flex;overflow:hidden;}

/* ── Full-screen camera area ── */
.cam-area{flex:1;position:relative;background:#000;overflow:hidden;min-width:0;border-right:1px solid var(--border);}

.view-label{position:absolute;bottom:10px;right:12px;font-family:var(--mono);font-size:9px;color:var(--accent);letter-spacing:2px;text-transform: uppercase;opacity:.5;z-index:10;pointer-events:none;}
#camera-img{width:100%;height:100%;object-fit:cover;display:none;} .camera-offline{position:absolute;inset:0;display:flex;flex-direction:column;align-items:center;justify-content:center;gap:8px;} .camera-offline .icon{font-size:28px;opacity:.2;}

.camera-offline p{font-family:var(--mono);font-size:9px;letter-spacing:2px;text-transform:uppercase;color:var(--muted);opacity:.5;}

/* ── Circular minimap (top-left overlay) ── */
#minimap-wrap{

position:absolute;top:14px;left:14px;
width:150px;height:150px;border-radius:50%; overflow:hidden;cursor:pointer;z-index:20;
border:2px solid rgba(0,212,255,.45);
background:rgba(8,12,16,.9);
box-shadow:0 0 24px rgba(0,212,255,.15), 0 4px 16px rgba(0,0,0,.6); transition:border-color .2s, box-shadow .2s;
}
#minimap-wrap:hover{

border-color:var(--accent);
box-shadow:0 0 32px rgba(0,212,255,.3), 0 4px 20px rgba(0,0,0,.7); }
#miniCanvas{width:100%;height:100%;display:block;}

.mini-badge{
position:absolute;bottom:0;left:0;right:0;text-align:center; padding:9px 0 7px;
background:linear-gradient(to top,rgba(8,12,16,.9),transparent); font-family:var(--mono);font-size:7px;letter-spacing:2px; color:var(--accent);pointer-events:none;
}

/* ── Full-screen map modal (covers camera area only) ── */ #map-modal{
display:none;position:absolute;inset:0;z-index:40; background:rgba(5,8,16,.96);flex-direction:column;
}
#map-modal.open{display:flex;}

#modal-hdr{

height:44px;flex-shrink:0;display:flex;align-items:center;gap:10px;
padding:0 14px;background:var(--surface);border-bottom:1px solid var(--border);
}
.modal-ttl{font-family:var(--mono);font-size:9px;color:var(--accent);letter-spacing:2px;text-transform:uppercase;} #modal-close{
margin-left:auto;
background:rgba(233,69,96,.1);border:1px solid rgba(233,69,96,.4); border-radius:4px;color:var(--danger);font-family:var(--mono); font-size:9px;letter-spacing:1px;padding:6px 14px;cursor:pointer; }
#modal-close:hover{background:rgba(233,69,96,.2);}

#modal-canvas{flex:1;display:block;width:100%;min-height:0;image-rendering:pixelated;}

/* ── Sidebar ── */
aside{width:210px;display:flex;flex-direction:column;background:var(--surface);overflow-y:auto;flex-shrink:0;} aside::-webkit-scrollbar{width:3px;}
aside::-webkit-scrollbar-thumb{background:var(--border);}
.card{border-bottom:1px solid var(--border);padding:12px 14px;} .card-title{font-family:var(--mono);font-size:9px;color:var(--muted);letter-spacing:2px;text-transform:uppercase;margin-bottom:8px;} .metric-big{font-family:var(--mono);font-size:26px;color:var(--accent);line-height:1;} .metric-unit{font-family:var(--mono);font-size:10px;color:var(--muted);margin-top:3px;} .pose-grid{display:grid;grid-template-columns:1fr 1fr;gap:5px;}
.pose-item{background:var(--panel);border:1px solid var(--border);border-radius:4px;padding:5px 7px;} .pose-key{font-family:var(--mono);font-size:9px;color:var(--accent);opacity:.6;} .pose-num{font-family:var(--mono);font-size:12px;color:var(--text);}

/* Toggle switches */
.toggle-row{display:flex;align-items:center;gap:8px;padding:3px 0;} .toggle-label{font-family:var(--mono);font-size:10px;color:var(--muted);} .toggle-switch{position:relative;width:32px;height:18px;cursor:pointer;}
.toggle-switch input{opacity:0;width:0;height:0;}
.toggle-track{position:absolute;inset:0;background:var(--panel);border:1px solid var(--border);border-radius:9px;transition:background .2s,border-color .2s;}

.toggle-track::after{content:'';position:absolute;top:2px;left:2px;width:12px;height:12px;border-radius:50%;background:var(--muted);transition:tr ansform .2s,background .2s;}
.toggle-switch input:checked+.toggle-track{background:rgba(0,212,255,.15);border-color:var(--accent);}
.toggle-switch input:checked+.toggle-track::after{transform:translateX(14px);background:var(--accent);}

/* Map save button */
.map-btn{background:var(--panel);border:1px solid var(--border);border-radius:4px;color:var(--accent);font-family:var(--mono);font-size:9px;letter-spacing:1px;padding:5px 8px;cursor:pointer;width:100%;margin-top:4px;}
.map-btn:active{background:rgba(0,212,255,.15);} .save-hint{font-family:var(--mono);font-size:8px;color:var(--muted);margin-top:5px;line-height:1.5;}

/* ── D-pad cross layout ── */
.controls-grid {
display: grid;
grid-template-columns: repeat(3, 1fr); grid-template-areas:
". fwd ."
"lft bck rgt"
"ap ap ap";
gap: 4px;
margin-top: 4px;
}
#btn-fwd { grid-area: fwd; } #btn-left { grid-area: lft; } #btn-back { grid-area: bck; } #btn-right { grid-area: rgt; }

#btn-auto { grid-area: ap; }

.ctrl-btn {
background:var(--panel);border:1px solid var(--border);border-radius:4px; color:var(--text);font-family:var(--mono);font-size:14px;
padding:8px 4px;cursor:pointer;text-align:center;
transition:background .12s,border-color .12s,color .12s;user-select:none; }
.ctrl-btn:active, .ctrl-btn.pressed { background:var(--accent);border-color:var(--accent);color:var(--bg);
}
.auto-btn {
background:rgba(0,255,136,.1);border-color:var(--accent2); color:var(--accent2);font-size:10px;letter-spacing:1px;padding:8px;
}
.auto-btn.active {
background:rgba(233,69,96,.15);border-color:var(--danger);color:var(--danger); }
.auto-btn:active { opacity:.8; }

/* Joystick */
.joystick-wrap{display:flex;flex-direction:column;align-items:center;gap:6px;padding-top:4px;} #joystick-canvas{display:block;cursor:grab;touch-action:none;border-radius:50%;} .joystick-vals{font-family:var(--mono);font-size:9px;color:var(--muted);letter-spacing:1px;} </style>
</head>
<body>

<header>
<div class="status-dot" id="dot"></div>
<div class="logo">ROBOT <span>AN NINH</span></div> <span id="conn-status">CONNECTING…</span>
<div class="header-right">
<span class="header-time" id="clock">--:--:--</span> </div>

</header>

<main>
<!-- ── Full-screen camera ── -->
<div class="cam-area">
<span class="view-label">▸ CAMERA · LIVE</span> <div class="camera-offline" id="cam-offline">
<div class="icon">📷</div><p>camera offline</p> </div>
<img id="camera-img" alt="camera">

<!-- Circular minimap — click to expand -->
<div id="minimap-wrap" title="Click to expand map">
<canvas id="miniCanvas" width="150" height="150"></canvas> <div class="mini-badge">▸ MAP ⊞</div>
</div>

<!-- Full-screen map modal (covers camera area only) -->
<div id="map-modal">
<div id="modal-hdr">
<span class="modal-ttl">▸ SLAM MAP · /map</span> <button id="modal-close">✕ Collapse</button> </div>
<canvas id="modal-canvas"></canvas>
</div>
</div>

<aside>
<!-- Speed / Angular rate -->
<div style="display:flex;border-bottom:1px solid var(--border);">
<div style="flex:1;padding:12px 10px;border-right:1px solid var(--border);"> <div class="card-title">Speed</div>
<div class="metric-big" id="speed" style="font-size:20px;">0.00</div> <div class="metric-unit">m/s</div>
</div>
<div style="flex:1;padding:12px 10px;">
<div class="card-title">Angular</div>
<div class="metric-big" id="angspeed" style="font-size:20px;">0.00</div> <div class="metric-unit">rad/s</div>
</div>
</div>

<!-- Robot pose -->
<div class="card">
<div class="card-title">Position · Heading</div>
<div class="pose-grid">
<div class="pose-item"><div class="pose-key">X</div><div class="pose-num" id="px">—</div></div> <div class="pose-item"><div class="pose-key">Y</div><div class="pose-num" id="py">—</div></div> <div class="pose-item" style="grid-column:1/-1">
<div class="pose-key">YAW (°)</div>
<div class="pose-num" id="pyaw">—°</div>
</div>
</div>
</div>

<!-- Display toggles -->
<div class="card">
<div class="card-title">Display</div>
<div class="toggle-row">
<label class="toggle-switch"><input type="checkbox" id="scan-chk" checked><div class="toggle-track"></div></label> <span class="toggle-label" id="scan-lbl">Scan ON</span>
</div>
<div class="toggle-row">
<label class="toggle-switch"><input type="checkbox" id="grid-chk" checked><div class="toggle-track"></div></label> <span class="toggle-label" id="grid-lbl">Grid 1m ON</span>
</div>
</div>

<!-- Save map -->
<div class="card">
<div class="card-title">Save Map</div>
<button class="map-btn" id="btn-save">💾 Serialize map</button>
<div class="save-hint" id="save-status">Flush pose graph → SD card</div> </div>

<!-- D-pad controls -->
<div class="card">
<div class="card-title">Controls</div>
<div class="controls-grid">
<button class="ctrl-btn" id="btn-fwd" data-lx="0.2" data-az="0" >↑</button> <button class="ctrl-btn" id="btn-left" data-lx="0" data-az="0.5" >←</button> <button class="ctrl-btn" id="btn-back" data-lx="-0.2" data-az="0" >↓</button> <button class="ctrl-btn" id="btn-right" data-lx="0" data-az="-0.5">→</button> <button class="ctrl-btn auto-btn" id="btn-auto">▶ AUTO NAV</button>
</div>

</div>

<!-- Joystick — flex:1 fills remaining sidebar space --> <div class="card" style="flex:1;">
<div class="card-title">Joystick</div>
<div class="joystick-wrap">
<canvas id="joystick-canvas" width="140" height="140"></canvas> <div class="joystick-vals" id="joy-vals">lx: 0.00 · az: 0.00</div> </div>
</div>
</aside>
</main>

<script>
// ── Configuration ─────────────────────────────────────────
const PI_HOST | = location.hostname;
const MAC_HOST | = 'vmuser-virtual-machine.local';
const ROS_URL | = `ws://${MAC_HOST}:9090`;
const CAM_URL | = `http://${PI_HOST}:8080/stream.mjpg`;
const RECONNECT_MS = 3000;
const BASE_PPM | = 40;
const MINI_PPM | = 12;
const LIDAR_X_OFFSET = 0.0;
const MAX_LINEAR = 0.3;
const MAX_ANGULAR = 0.8;

// ── Clock ───────────────────────────────────────────────── setInterval(() => {
document.getElementById('clock').textContent = new Date().toLocaleTimeString('en-GB', {hour12:false}); }, 1000);

// ── ROS Connection State ──────────────────────────────────
const dot = document.getElementById('dot');
const connStat = document.getElementById('conn-status');
let _cv | = null;
let _mode | = null;
let autoMode = false;
let _rosOK | = false;
let topics | = {};

const ros = new ROSLIB.Ros({ url: ROS_URL });

ros.on('connection', () => {
_rosOK = true;
dot.classList.add('ok');
connStat.textContent = `CONNECTED · ${MAC_HOST}:9090`; subscribeTopics();
});

ros.on('error', () => {
_rosOK = false;
connStat.textContent = `ERROR · ${MAC_HOST}:9090`; });

ros.on('close', () => {
_rosOK = false;
dot.classList.remove('ok');
connStat.textContent = `DISCONNECTED · retry ${RECONNECT_MS/1000}s…`;

if (autoMode) {
autoMode = false;
const b = document.getElementById('btn-auto');
b.classList.remove('active');
b.textContent = '▶ AUTO NAV';
}

unsubscribeTopics();
setTimeout(() => {
connStat.textContent = `RECONNECTING → ${MAC_HOST}:9090`; ros.connect(ROS_URL);
}, RECONNECT_MS);
});

function unsubscribeTopics() {
for (const key in topics) {
if (topics[key]) topics[key].unsubscribe(); }
topics = {};
}

// ── Publishers ──────────────────────────────────────────── function sendVel(lx, az) {
if (!_rosOK) return;
if (!_cv) _cv = new ROSLIB.Topic({ ros, name:'/cmd_vel', messageType:'geometry_msgs/Twist' }); _cv.publish(new ROSLIB.Message({ linear:{x:lx, y:0, z:0}, angular:{x:0, y:0, z:az} }));

}

function sendMode(mode) {
if (!_rosOK) return;
if (!_mode) _mode = new ROSLIB.Topic({ ros, name:'/robot_mode', messageType:'std_msgs/String' }); _mode.publish(new ROSLIB.Message({ data: mode }));
}

// ── SLAM Map State ────────────────────────────────────────
let mapInfo=null, mapBitmap=null, robotPose=null;
let scanPoints=[], showScan=true, showGrid=true, _raf=false;
let mapModalOpen = false;

const miniCanvas = document.getElementById('miniCanvas'); const miniCtx = miniCanvas.getContext('2d');
const modalCanvas = document.getElementById('modal-canvas'); const modalCtx = modalCanvas.getContext('2d');

function scheduleRedraw() {
if (_raf) return; _raf=true;
requestAnimationFrame(() => {
_raf=false;
redrawMini();
if (mapModalOpen) redrawModal(); });
}

function buildBitmap(msg) {
const w = msg.info.width, h = msg.info.height; const img = new ImageData(w, h), d = msg.data; for (let row = 0; row < h; row++) {
const ro = (h - 1 - row) * w, co = row * w * 4; for (let col = 0; col < w; col++) {
const v = d[ro + col]; let r, g, b;
if (v === -1) { r = 30; g = 40; b = 50; }
else if (v === 0) { r = 230; g = 235; b = 240; }
else { r = 10; g = 20; b = 30; }
const p = co + col * 4;
img.data[p] = r; img.data[p+1] = g; img.data[p+2] = b; img.data[p+3] = 255; }
}
return createImageBitmap(img);
}

function renderMap(ctx, W, H, ppm) {
const wcx = robotPose ? robotPose.x : (mapInfo ? mapInfo.origin.position.x + mapInfo.width * mapInfo.resolution / 2 : 0); const wcy = robotPose ? robotPose.y : (mapInfo ? mapInfo.origin.position.y + mapInfo.height * mapInfo.resolution / 2 : 0);

ctx.fillStyle = '#050810'; ctx.fillRect(0,0,W,H);

if (showGrid) {
const G = 1.0;
const wL = wcx - W/(2*ppm), wR = wcx + W/(2*ppm), wT = wcy + H/(2*ppm), wB = wcy - H/(2*ppm); ctx.save(); ctx.setLineDash([2,4]); ctx.lineWidth = 0.5;
for (let wx = Math.ceil(wL/G)*G; wx <= wR+G; wx += G) {
const cx = W/2 + (wx - wcx)*ppm;
ctx.strokeStyle = Math.round(wx)%5===0 ? 'rgba(0,212,255,0.18)' : 'rgba(0,212,255,0.07)'; ctx.beginPath(); ctx.moveTo(cx,0); ctx.lineTo(cx,H); ctx.stroke();
if (ppm >= 20 && Math.round(wx)%5===0) {
ctx.fillStyle = 'rgba(0,212,255,0.4)'; ctx.font = "9px 'Share Tech Mono',monospace"; ctx.fillText(Math.round(wx)+'m', cx+2, H-4);
}
}
for (let wy = Math.floor(wT/G)*G; wy >= wB-G; wy -= G) {
const cy = H/2 - (wy - wcy)*ppm;
ctx.strokeStyle = Math.round(wy)%5===0 ? 'rgba(0,212,255,0.18)' : 'rgba(0,212,255,0.07)'; ctx.beginPath(); ctx.moveTo(0,cy); ctx.lineTo(W,cy); ctx.stroke();
if (ppm >= 20 && Math.round(wy)%5===0 && Math.round(wy)!==0) {
ctx.fillStyle = 'rgba(0,212,255,0.4)'; ctx.font = "9px 'Share Tech Mono',monospace"; ctx.fillText(Math.round(wy)+'m', 2, cy-2);
}
}
ctx.setLineDash([]); ctx.restore();
}

if (mapBitmap && mapInfo) {
const res = mapInfo.resolution, mw = mapInfo.width, mh = mapInfo.height;
const ox = mapInfo.origin.position.x, oy = mapInfo.origin.position.y;
ctx.imageSmoothingEnabled = false;
ctx.drawImage(mapBitmap, W/2 + (ox - wcx)*ppm, H/2 - (oy - wcy)*ppm - mh*res*ppm, mw*res*ppm, mh*res*ppm); }

if (showScan && scanPoints.length > 0) {
const d = ppm >= 20 ? 2.5 : 1.5;
ctx.save(); ctx.fillStyle = '#00ffff';

for (const pt of scanPoints) ctx.fillRect(W/2 + (pt.x - wcx)*ppm - d/2, H/2 - (pt.y - wcy)*ppm - d/2, d, d); ctx.restore();
}

if (robotPose) {
const cx = W/2, cy = H/2, r = ppm >= 20 ? 8 : 5, yaw = robotPose.yaw; ctx.save();
if (ppm >= 20) {
ctx.beginPath(); ctx.arc(cx,cy,r+4,0,2*Math.PI);
ctx.strokeStyle = 'rgba(233,69,96,0.3)'; ctx.lineWidth = 2; ctx.stroke(); }
ctx.beginPath(); ctx.arc(cx,cy,r,0,2*Math.PI);
ctx.fillStyle = '#e94560'; ctx.fill();
ctx.strokeStyle = 'rgba(255,255,255,0.7)'; ctx.lineWidth = 1.5; ctx.stroke(); ctx.beginPath(); ctx.moveTo(cx,cy);
ctx.lineTo(cx + r*2.8*Math.cos(yaw), cy - r*2.8*Math.sin(yaw)); ctx.strokeStyle = '#fff'; ctx.lineWidth = 2; ctx.lineCap = 'round'; ctx.stroke(); ctx.restore();
}

if (ppm >= 20) {
const sx = W - ppm - 16, sy = H - 16;
ctx.save(); ctx.strokeStyle = '#00d4ff'; ctx.lineWidth = 2; ctx.lineCap = 'square'; ctx.beginPath(); ctx.moveTo(sx,sy); ctx.lineTo(sx+ppm,sy); ctx.stroke(); ctx.beginPath(); ctx.moveTo(sx,sy-4); ctx.lineTo(sx,sy+4); ctx.stroke(); ctx.beginPath(); ctx.moveTo(sx+ppm,sy-4); ctx.lineTo(sx+ppm,sy+4); ctx.stroke(); ctx.fillStyle = '#00d4ff'; ctx.font = "9px 'Share Tech Mono',monospace"; ctx.textAlign = 'center'; ctx.fillText('1 m', sx+ppm/2, sy-6);
ctx.textAlign = 'left'; ctx.restore();
}
}

function redrawMini() {
miniCanvas.width = miniCanvas.offsetWidth || 150; miniCanvas.height = miniCanvas.offsetHeight || 150; renderMap(miniCtx, miniCanvas.width, miniCanvas.height, MINI_PPM); }
function redrawModal() {
const W = modalCanvas.offsetWidth, H = modalCanvas.offsetHeight; if (!W || !H) return;
modalCanvas.width = W; modalCanvas.height = H;
renderMap(modalCtx, W, H, BASE_PPM);
}

// ── ROS Subscriptions ───────────────────────────────────── function subscribeTopics() {
topics.map = new ROSLIB.Topic({ ros, name:'/map', messageType:'nav_msgs/OccupancyGrid' }); topics.map.subscribe(async msg => {
mapInfo = msg.info; mapBitmap = await buildBitmap(msg); scheduleRedraw();
});

topics.scan = new ROSLIB.Topic({ ros, name:'/scan_filtered', messageType:'sensor_msgs/LaserScan', throttle_rate:100, queue_length:1 }); topics.scan.subscribe(msg => {
const pts=[], am=msg.angle_min, ai=msg.angle_increment, rm=msg.range_min, rx_=msg.range_max;
const px=robotPose?robotPose.x:0, py=robotPose?robotPose.y:0, yaw=robotPose?robotPose.yaw:0;
const c=Math.cos(yaw), s=Math.sin(yaw);
for (let i=0; i<msg.ranges.length; i++) {
const r = msg.ranges[i];
if (!isFinite(r) || r<rm || r>rx_) continue;
const a = am + i*ai, bx = r*Math.cos(a) + LIDAR_X_OFFSET, by = r*Math.sin(a); pts.push({x: px + c*bx - s*by, y: py + s*bx + c*by});
}
scanPoints = pts; scheduleRedraw();
});

topics.pose = new ROSLIB.Topic({ ros, name:'/robot_pose', messageType:'geometry_msgs/PoseStamped' }); topics.pose.subscribe(msg => {
const q = msg.pose.orientation;
const yaw = Math.atan2(2*(q.w*q.z + q.x*q.y), 1 - 2*(q.y*q.y + q.z*q.z));
robotPose = {x: msg.pose.position.x, y: msg.pose.position.y, yaw}; document.getElementById('px').textContent = robotPose.x.toFixed(3); document.getElementById('py').textContent = robotPose.y.toFixed(3); document.getElementById('pyaw').textContent = (yaw*180/Math.PI).toFixed(1)+'°';
if (mapInfo && mapBitmap) scheduleRedraw();
});

topics.odom = new ROSLIB.Topic({ ros, name:'/odom', messageType:'nav_msgs/Odometry' }); topics.odom.subscribe(msg => {
document.getElementById('speed').textContent = msg.twist.twist.linear.x.toFixed(2); document.getElementById('angspeed').textContent = msg.twist.twist.angular.z.toFixed(2); });
}

// ── UI Events ───────────────────────────────────────────── document.getElementById('minimap-wrap').addEventListener('click', () => {

mapModalOpen = true;
document.getElementById('map-modal').classList.add('open'); setTimeout(redrawModal, 10);
});
document.getElementById('modal-close').addEventListener('click', () => { mapModalOpen = false;
document.getElementById('map-modal').classList.remove('open');
});
new ResizeObserver(() => { if (mapModalOpen) redrawModal(); }).observe(document.getElementById('modal-canvas'));

document.getElementById('scan-chk').addEventListener('change', e => {
showScan = e.target.checked;
document.getElementById('scan-lbl').textContent = showScan ? 'Scan ON' : 'Scan OFF';
scheduleRedraw();
});
document.getElementById('grid-chk').addEventListener('change', e => {
showGrid = e.target.checked;
document.getElementById('grid-lbl').textContent = showGrid ? 'Grid 1m ON' : 'Grid OFF'; scheduleRedraw();
});

document.getElementById('btn-save').addEventListener('click', () => {
if (!_rosOK) { document.getElementById('save-status').textContent='❌ Not connected'; return; }
const fname = '/home/ubuntu/map_' + Date.now();
document.getElementById('save-status').textContent = '⏳ Saving…';
new ROSLIB.Service({ros, name:'/slam_toolbox/serialize_pose_graph', serviceType:'slam_toolbox/SerializePoseGraph'}) .callService(new ROSLIB.ServiceRequest({filename:fname}),
() => { document.getElementById('save-status').textContent = '✅ ' + fname; },
err => { document.getElementById('save-status').textContent = '❌ ' + err; }
);
});

const camImg = document.getElementById('camera-img');
const camOff = document.getElementById('cam-offline');
function loadCam() { camImg.src = CAM_URL + '?t=' + Date.now(); }
camImg.onload = () => { camImg.style.display = 'block'; camOff.style.display = 'none'; };
camImg.onerror = () => { camImg.style.display = 'none'; camOff.style.display = 'flex'; setTimeout(loadCam, 4000); }; loadCam();

document.querySelectorAll('.ctrl-btn[data-lx]').forEach(btn => {
const lx = parseFloat(btn.dataset.lx), az = parseFloat(btn.dataset.az);
const release = () => { btn.classList.remove('pressed'); sendVel(0,0); };
btn.addEventListener('pointerdown', e => { e.preventDefault(); btn.classList.add('pressed'); sendVel(lx,az); }); btn.addEventListener('pointerup', release);
btn.addEventListener('pointerleave', () => { if (btn.classList.contains('pressed')) release(); }); btn.addEventListener('pointercancel', release);
});

document.getElementById('btn-auto').addEventListener('click', () => {
autoMode = !autoMode;
const btn = document.getElementById('btn-auto');
if (autoMode) {
btn.classList.add('active');
btn.textContent = '■ STOP AUTO'; sendMode('AUTO');
} else {
btn.classList.remove('active'); btn.textContent = '▶ AUTO NAV'; sendMode('MANUAL');
sendVel(0,0);
}
});

// ── Keyboard Controls ───────────────────────────────────── const keys = new Set();
let isJoyActive = false; // Prevent Joystick & Keyboard conflicts

function clearDpad() {
document.querySelectorAll('.ctrl-btn[data-lx]').forEach(b => b.classList.remove('pressed')); }

document.addEventListener('keydown', e => {
const k = e.key.toLowerCase(); // Fix CapsLock sticky bug
if ([' ', 'arrowup', 'arrowdown', 'arrowleft', 'arrowright'].includes(k)) e.preventDefault(); if (k === ' ') { keys.clear(); sendVel(0,0); clearDpad(); return; }
if (isJoyActive || keys.has(k)) return;
keys.add(k);
applyKeys();
});

document.addEventListener('keyup', e => { const k = e.key.toLowerCase(); keys.delete(k);
if (!isJoyActive) applyKeys();
});

function applyKeys() {
if (isJoyActive) return;

const up = keys.has('arrowup') || keys.has('w'); const down = keys.has('arrowdown') || keys.has('s'); const left = keys.has('arrowleft') || keys.has('a'); const right = keys.has('arrowright') || keys.has('d');

let lx = 0, az = 0;
if (up) lx = 0.2;
if (down) lx = -0.2;
if (left) az = 0.5;
if (right) az = -0.5;
sendVel(lx, az);

clearDpad();
if (up) document.getElementById('btn-fwd') ?.classList.add('pressed'); if (down) document.getElementById('btn-back') ?.classList.add('pressed'); if (left) document.getElementById('btn-left') ?.classList.add('pressed');
if (right) document.getElementById('btn-right')?.classList.add('pressed');
}

// ── Analog Joystick ─────────────────────────────────────── (function(){
const jc = document.getElementById('joystick-canvas');
const jx = jc.getContext('2d');
const CX = 70, CY = 70, OR = 64, IR = 22, DEAD = 0.08; let active = false, sx = 0, sy = 0, af = null;

function draw(){
jx.clearRect(0,0,140,140);
jx.beginPath(); jx.arc(CX,CY,OR,0,2*Math.PI);
jx.strokeStyle = 'rgba(0,212,255,0.2)'; jx.lineWidth = 1.5; jx.stroke(); jx.strokeStyle = 'rgba(0,212,255,0.07)'; jx.lineWidth = 1;
jx.beginPath(); jx.moveTo(CX,CY-OR); jx.lineTo(CX,CY+OR); jx.stroke(); jx.beginPath(); jx.moveTo(CX-OR,CY); jx.lineTo(CX+OR,CY); jx.stroke(); jx.beginPath(); jx.arc(CX,CY,OR*.5,0,2*Math.PI);
jx.strokeStyle = 'rgba(0,212,255,0.06)'; jx.stroke();

const kx = CX + sx * OR, ky = CY + sy * OR;
jx.beginPath(); jx.moveTo(CX,CY); jx.lineTo(kx,ky);
jx.strokeStyle = active ? 'rgba(233,69,96,0.5)' : 'rgba(0,212,255,0.25)'; jx.lineWidth = 1.5; jx.stroke();

const g = jx.createRadialGradient(kx,ky,0,kx,ky,IR*1.6); g.addColorStop(0, active ? 'rgba(233,69,96,0.3)' : 'rgba(0,212,255,0.15)'); g.addColorStop(1, 'transparent');
jx.beginPath(); jx.arc(kx,ky,IR*1.6,0,2*Math.PI); jx.fillStyle = g; jx.fill();

const col = active ? '#e94560' : '#00d4ff';
jx.beginPath(); jx.arc(kx,ky,IR,0,2*Math.PI);
jx.fillStyle = col + '33'; jx.fill();
jx.strokeStyle = col; jx.lineWidth = 1.5; jx.stroke();

jx.beginPath(); jx.arc(CX,CY,3,0,2*Math.PI); jx.fillStyle = 'rgba(0,212,255,0.3)'; jx.fill();
}

function pos(e){
const rc = jc.getBoundingClientRect(), pt = e.touches ? e.touches[0] : e; return {x: (pt.clientX - rc.left - CX) / OR, y: (pt.clientY - rc.top - CY) / OR}; }

function clamp(x,y){
const d = Math.sqrt(x*x + y*y);
return d > 1 ? {x: x/d, y: y/d} : {x,y};
}

function applyJoy(){
const lx = Math.abs(sy) > DEAD ? -sy * MAX_LINEAR : 0;
const az = Math.abs(sx) > DEAD ? -sx * MAX_ANGULAR : 0; document.getElementById('joy-vals').textContent = `lx:${lx.toFixed(2)} · az:${az.toFixed(2)}`; sendVel(lx, az);
}

function start(e){
e.preventDefault();
active = true;
isJoyActive = true; // Disable keyboard while joystick is active jc.style.cursor = 'grabbing';
move(e);
}

function move(e){

if(!active) return;
e.preventDefault();
const p = pos(e), c = clamp(p.x, p.y);
sx = c.x; sy = c.y;
cancelAnimationFrame(af);
af = requestAnimationFrame(() => { draw(); applyJoy(); }); }

function end(){
active = false;
isJoyActive = false; // Re-enable keyboard after joystick released jc.style.cursor = 'grab';
function sp(){
sx *= .7; sy *= .7;
if(Math.abs(sx) < .01 && Math.abs(sy) < .01){
sx = sy = 0; draw(); applyJoy(); return;
}
draw(); applyJoy(); af = requestAnimationFrame(sp);
}
cancelAnimationFrame(af); af = requestAnimationFrame(sp);
}

jc.addEventListener('mousedown', start); window.addEventListener('mousemove', e => { if(active) move(e); }); window.addEventListener('mouseup', end); jc.addEventListener('touchstart', start, {passive:false}); jc.addEventListener('touchmove', move, {passive:false}); jc.addEventListener('touchend', end); jc.addEventListener('touchcancel', end);

draw();
redrawMini();
})();
</script>
</body>
</html>

# Cài trên Mac

## 1.1. Cài đặt cơ bản ubuntu: - Cập nhật hệ điều hành:

sudo apt update && sudo apt upgrade -y
sudo reboot

## - Cài bộ đồng bộ thời gian:

sudo apt update && sudo apt install chrony -y

## 1.2. CycloneDDS Cross-Machine (Pi ↔ Mac VM)”

sudo apt update
sudo apt install -y avahi-daemon
sudo systemctl enable --now avahi-daemon

## - Cấu hình mạng lõi

cat > ~/cyclone_dds.xml << 'EOF' <?xml version="1.0" encoding="utf-8"?> <CycloneDDS>
<Domain>
<General>
<NetworkInterfaceAddress>auto</NetworkInterfaceAddress> </General>
<Discovery>
<Peers>
<Peer address="robotanninh.local"/> </Peers>
</Discovery>
</Domain>
</CycloneDDS>
EOF

## 1.3. Cài đặt ROS2: - Thiết lập Locale

sudo apt update && sudo apt install locales -y
sudo locale-gen en_US en_US.UTF-8
sudo update-locale LC_ALL=en_US.UTF-8 LANG=en_US.UTF-8 export LANG=en_US.UTF-8

## - Bật Universe:

sudo apt install software-properties-common -y
sudo add-apt-repository universe -y

## - Thêm key bảo mật và nguồn tải ROS 2:

sudo apt update && sudo apt install curl -y
export ROS_APT_SOURCE_VERSION=$(curl -s https://api.github.com/repos/ros-infrastructure/ros-apt-source/releases/latest | grep -F
"tag_name" | awk -F'"' '{print $4}')
curl -L -o /tmp/ros2-apt-source.deb "https://github.com/ros-infrastructure/ros-apt-source/releases/download/${ROS_APT_SOURCE_VERSION}/ros2-apt-source_${ROS_APT_SOURCE_VERSION}.$(. /etc/os-release && echo ${UBUNTU_CODENAME:-${VERSION_CODENAME}})_all.deb"
sudo dpkg -i /tmp/ros2-apt-source.deb

## - Cài đặt ROS 2 Humble Desktop và các Tool:

sudo apt update && sudo apt upgrade -y
sudo apt install ros-humble-desktop ros-dev-tools -y

## 1.4. Cài đặt các gói thuật toán SLAM, EKF và Nav2

sudo apt install ros-humble-slam-toolbox ros-humble-navigation2 ros-humble-nav2-bringup ros-humble-robot-localization ros-humble-rmw-cyclonedds-cpp ros-humble-rosbridge-suite -y

## 1.5. Cấu hình môi trường tự động:

echo 'source /opt/ros/humble/setup.bash' >> ~/.bashrc
echo 'export RMW_IMPLEMENTATION=rmw_cyclonedds_cpp' >> ~/.bashrc echo 'export ROS_DOMAIN_ID=42' >> ~/.bashrc
source ~/.bashrc

## 1.6. Khởi tạo Workspace và tải mã nguồn thuật toán

mkdir -p ~/ros2_ws/src
cd ~/ros2_ws/src

git clone -b humble-devel https://github.com/Adlink-ROS/rf2o_laser_odometry.git

ros2 pkg create mac_brain --build-type ament_python
mkdir -p ~/ros2_ws/config
mkdir -p ~/ros2_ws/src/mac_brain/launch

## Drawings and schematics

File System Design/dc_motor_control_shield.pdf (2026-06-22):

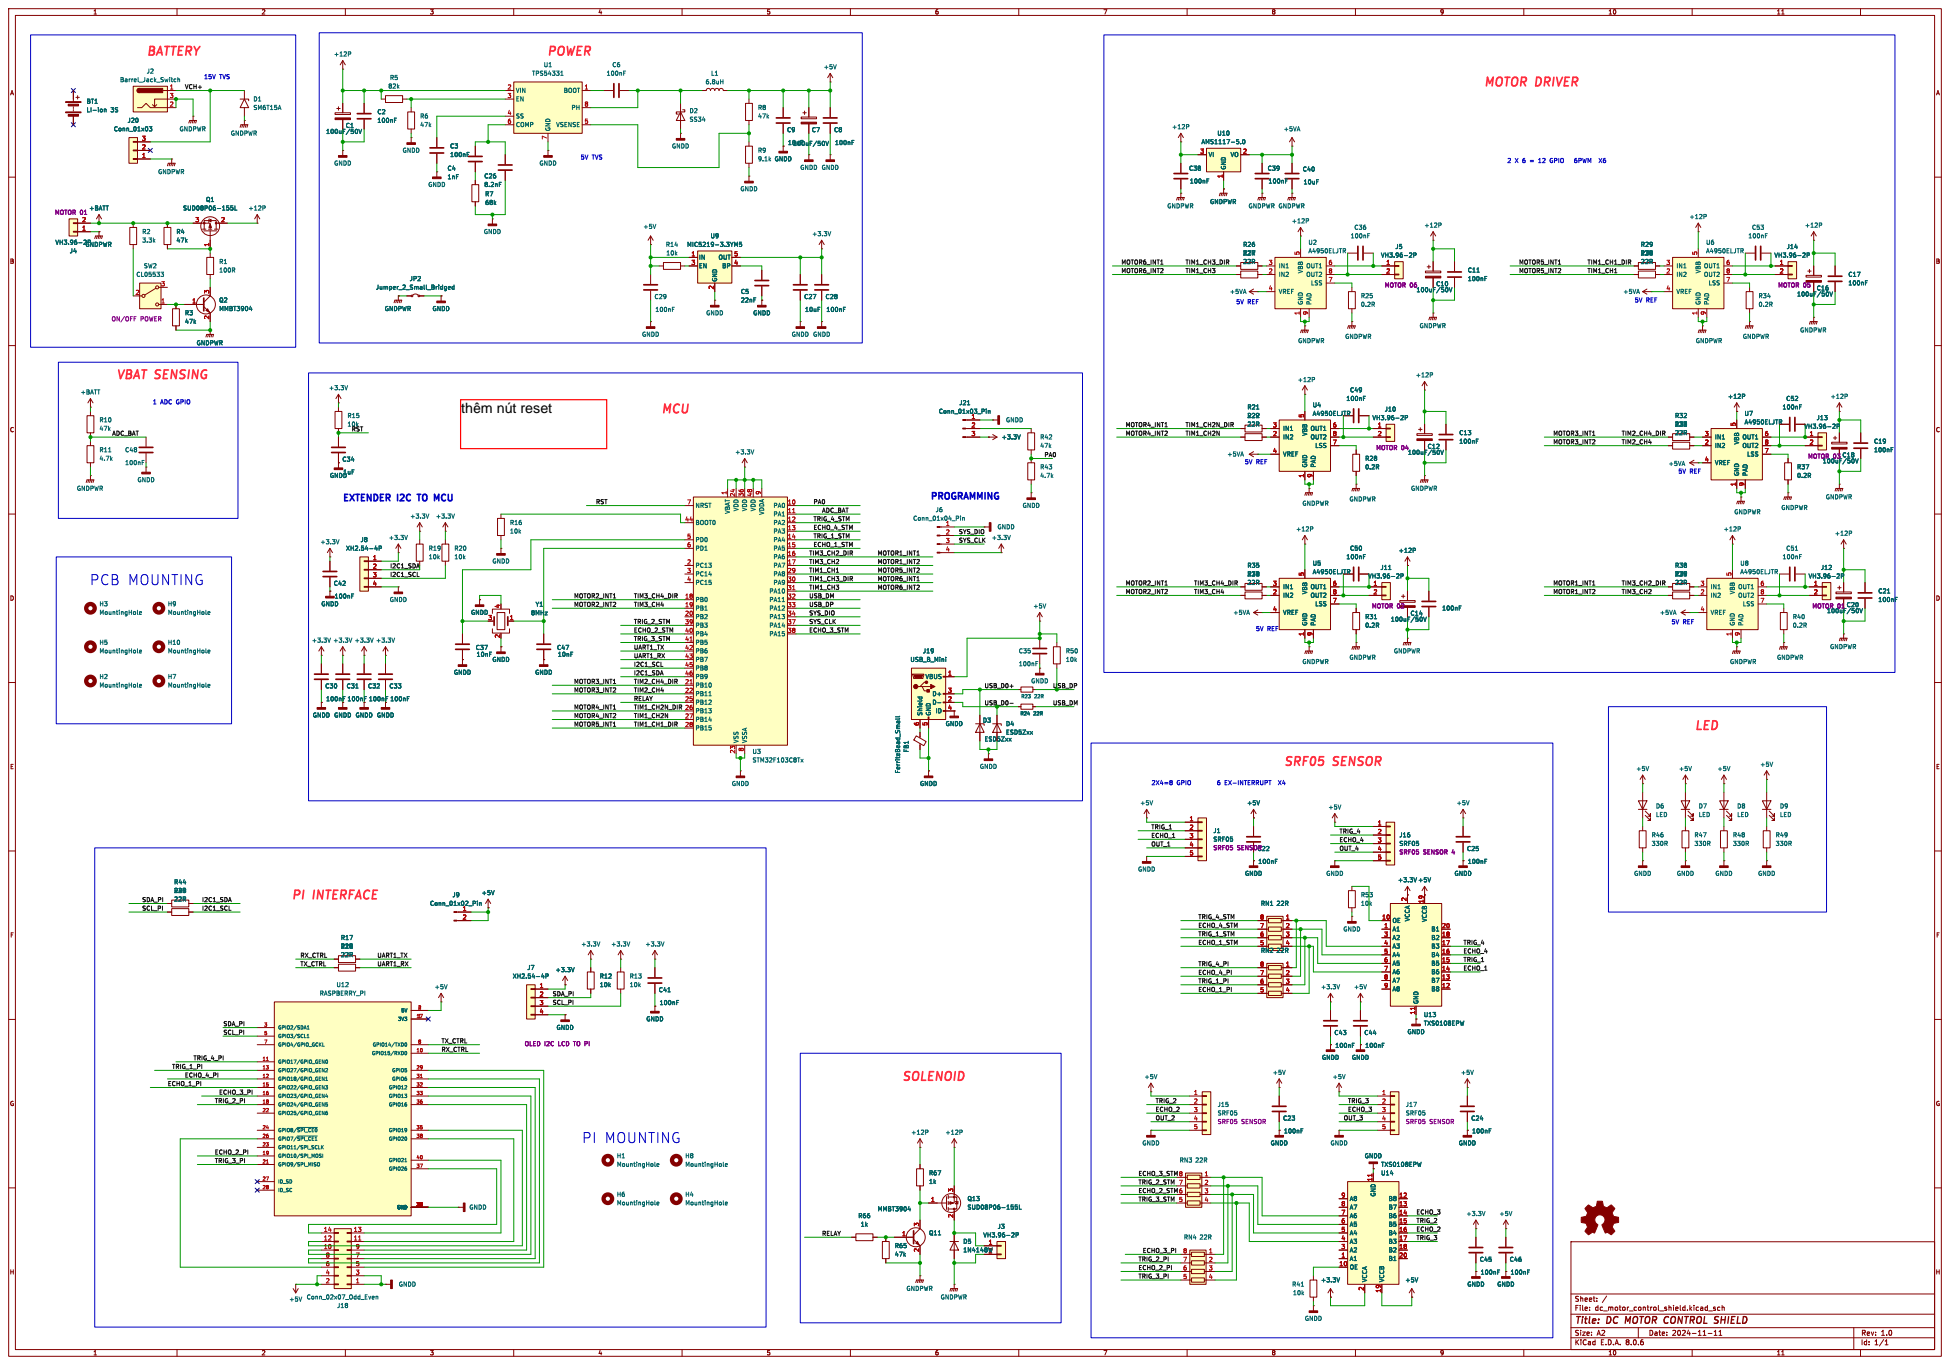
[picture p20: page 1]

2 EN 3 BP 4 OUT 5 U9 MIC5219-3.3YM5 GNDD

1 PA0 10 PA1 11 PA2 12 PA3 13 PA4 14 PA5 15 PA6 16 PA7 17 PB0 18 PB1 19 PC13 2 PB2 20 PB10 21 PB11 22 VSS 23 VDD 24 PB12 25 PB13 26 PB14 27 PB15 28 PA8 29 PC14 3 PA9 30 PA10 31 PA11 32 PA12 33 PA13 34 VDD 36 PA14 37 PA15 38 PB3 39 PC15 4 PB4 40 PB5 41 PB6 42 PB7 43 BOOT0 44 PB8 45 PB9 46 VDD 48 PD0 5 PD1 6 NRST 7 VSSA

J7 XH2.54-4P OLED I2C LCD TO PI 1

+3.3V GNDD

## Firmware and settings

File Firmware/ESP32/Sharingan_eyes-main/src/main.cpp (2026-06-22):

#include <Arduino.h>
#include <SPI.h>
#include <TFT_eSPI.h>
#include "config.h"


/**************************************************************
*   Definitions
***************************************************************/
#define USE_DMA
#define AUTO_SWITCH_INTERVAL 5000 

// A pixel buffer is used during eye rendering
#define BUFFER_SIZE 1024 // 128 to 1024 seems optimum

#ifdef USE_DMA
  #define BUFFERS 2      // 2 toggle buffers with DMA
#else
  #define BUFFERS 1      // 1 buffer for no DMA
#endif

/**************************************************************
*   Type definitions
***************************************************************/
typedef struct              
{
  int8_t  select;       // pin numbers for each eye's screen select line
  int8_t  wink;         // and wink button (or -1 if none) specified there,
  uint8_t rotation;     // also display rotation and the x offset
  int16_t xposition;    // position of eye on the screen
} eyeInfo_t;

// A simple state machine is used to control eye blinks/winks:
#define NOBLINK 0       // Not currently engaged in a blink
#define ENBLINK 1       // Eyelid is currently closing
#define DEBLINK 2       // Eyelid is currently opening
typedef struct 
{
  uint8_t  state;       // NOBLINK/ENBLINK/DEBLINK
  uint32_t duration;    // Duration of blink state (micros)
  uint32_t startTime;   // Time (micros) of last state change
} eyeBlink;

// One-per-eye structure
typedef struct 
{
  int16_t   tft_cs;     // Chip select pin for each display
  eyeBlink  blink;      // Current blink/wink state
  int16_t   xposition;  // x position of eye image
} eye_t;

/**************************************************************
*   Local variables
***************************************************************/
static TFT_eSPI tft;                            // A single instance is used for 1 or 2 displays

static uint16_t pbuffer[BUFFERS][BUFFER_SIZE]; // Pixel rendering buffer
static bool     dmaBuf   = 0;                  // DMA buffer selection

static eye_t eye[NUM_EYES];

// This table contains ONE LINE PER EYE.  The table MUST be present with
// this name and contain ONE OR MORE lines.  Each line contains THREE items:
// a pin number for the corresponding TFT/OLED display's SELECT line, a pin
// pin number for that eye's "wink" button (or -1 if not used), a screen
// rotation value (0-3) and x position offset for that eye.
#if (NUM_EYES == 2)
  eyeInfo_t eyeInfo[] = {
    { TFT1_CS, LH_WINK_PIN, TFT_1_ROT, EYE_1_XPOSITION }, // LEFT EYE chip select and wink pins, rotation and offset
    { TFT2_CS, RH_WINK_PIN, TFT_2_ROT, EYE_2_XPOSITION }, // RIGHT EYE chip select and wink pins, rotation and offset
  };
#else
  eyeInfo_t eyeInfo[] = {
    { TFT1_CS, LH_WINK_PIN, TFT_1_ROT, EYE_1_XPOSITION }, // EYE chip select and wink pins, rotation and offset
  };
#endif

#if !defined(LIGHT_PIN) || (LIGHT_PIN < 0)
// Autonomous iris motion uses a fractal behavior to similate both the major
// reaction of the eye plus the continuous smaller adjustments that occur.
static uint16_t oldIris = (IRIS_MIN + IRIS_MAX) / 2, newIris;
#endif

// Cac loi mat (iris) doi duoc luc chay bang nut bam.
// Loi co scaleMin == scaleMax == 120 la loi "phang": texture phu kin
// toan bo vong iris (kieu Sharingan), khong gian/co dong tu.
typedef struct
{
    const uint16_t *map; // texture iris 256x64 (polar map)
    uint16_t scaleMin;   // iScale khi dong tu gian to nhat
    uint16_t scaleMax;   // iScale khi dong tu co nho nhat
} irisStyle_t;

// iScale 121 (KHONG dung 120): pixel ngoai vong tron iris mang ma polar
// dist=127, can 121*127/240 = 64 >= IRIS_MAP_HEIGHT de roi ra sclera;
// voi 120 chung roi vao hang 63 cua texture lam iris bi VUONG.
static const irisStyle_t irisStyles[] = {
    { iris,          IRIS_MIN, IRIS_MAX }, // mat nau mac dinh
    { iris_tomoe,    121, 121 },           // Sharingan tomoe
    { iris_kamui,    121, 121 },           // Mangekyou Kamui
    { iris_sasuke,   121, 121 },           // Mangekyou vinh hang (Sasuke)
    { iris_rinnegan, 121, 121 },           // Rinnegan
};
#define NUM_IRIS_STYLES (sizeof(irisStyles) / sizeof(irisStyles[0]))

static const char *irisStyleNames[] = {
    "mat nau", "Sharingan tomoe", "Mangekyou Kamui", "Mangekyou Sasuke", "Rinnegan",
};

// Khoi dong thang vao loi Sasuke (index 3) de kiem tra
static uint8_t irisStyleIndex = 3;
static const uint16_t *curIris = iris_sasuke;
static uint16_t curIrisMin = 121, curIrisMax = 121;

// Doc nut doi loi mat. Phai goi tu frame() (moi khung hinh) vi split()
// chan loop() lien tuc ca chuc giay.
static void checkIrisButton(void)
{
    static uint32_t lastSwitch = 0;

    // --- Nut bam thu cong (neu co) ---
#if defined(IRIS_SWITCH_PIN) && (IRIS_SWITCH_PIN >= 0)
    static bool lastState = HIGH;
    static uint32_t lastEdge = 0;

    bool s = digitalRead(IRIS_SWITCH_PIN);
    if (s != lastState && millis() - lastEdge > 200)
    {
        lastEdge = millis();
        lastState = s;
        if (s == LOW)
        {
            irisStyleIndex = (irisStyleIndex + 1) % NUM_IRIS_STYLES;
            curIris    = irisStyles[irisStyleIndex].map;
            curIrisMin = irisStyles[irisStyleIndex].scaleMin;
            curIrisMax = irisStyles[irisStyleIndex].scaleMax;
            lastSwitch = millis(); // Reset timer khi bam nut
            Serial.print("Doi loi mat (nut) -> ");
            Serial.println(irisStyleNames[irisStyleIndex]);
        }
    }
#endif

    // --- Tu dong doi theo thoi gian ---
    if (millis() - lastSwitch >= AUTO_SWITCH_INTERVAL)
    {
        lastSwitch = millis();
        irisStyleIndex = (irisStyleIndex + 1) % NUM_IRIS_STYLES;
        curIris    = irisStyles[irisStyleIndex].map;
        curIrisMin = irisStyles[irisStyleIndex].scaleMin;
        curIrisMax = irisStyles[irisStyleIndex].scaleMax;
        Serial.print("Doi loi mat (tu dong) -> ");
        Serial.println(irisStyleNames[irisStyleIndex]);
    }
}

static uint32_t startTime;

/**************************************************************
*   Local Functions
***************************************************************/
static void initEyes(void);
static void updateEye(void);
static void drawEye(uint8_t  e, uint32_t iScale, uint32_t scleraX, uint32_t scleraY, uint32_t uT, uint32_t lT);
static void frame(uint16_t iScale);
static void split(int16_t  startValue, int16_t  endValue, uint32_t startTime, int32_t  duration, int16_t  range);  


void setup(void)
{
    Serial.begin(115200);
    Serial.println("Starting");

#if defined(DISPLAY_BACKLIGHT) && (DISPLAY_BACKLIGHT >= 0)
    // Enable backlight pin, initially off
    Serial.println("Backlight turned off");
    pinMode(DISPLAY_BACKLIGHT, OUTPUT);
    digitalWrite(DISPLAY_BACKLIGHT, LOW);
#endif

#if defined(IRIS_SWITCH_PIN) && (IRIS_SWITCH_PIN >= 0)
    pinMode(IRIS_SWITCH_PIN, INPUT_PULLUP); // Nut doi loi mat
#endif

    // Initialise the eye(s), this will set all chip selects low for the tft.init()
    initEyes();

    // Initialise TFT
    Serial.println("Initialising displays");
    tft.init();

#ifdef USE_DMA
    Serial.println("Initialising DMA");
    tft.initDMA();
#endif

    // Raise chip select(s) so that displays can be individually configured
    digitalWrite(eye[0].tft_cs, HIGH);

    if (NUM_EYES > 1)
    {
        digitalWrite(eye[1].tft_cs, HIGH);
    }

    for (uint8_t e = 0; e < NUM_EYES; e++)
    {
        digitalWrite(eye[e].tft_cs, LOW);
        tft.setRotation(eyeInfo[e].rotation);
        tft.fillScreen(TFT_BLACK);
        digitalWrite(eye[e].tft_cs, HIGH);
    }

#if defined(DISPLAY_BACKLIGHT) && (DISPLAY_BACKLIGHT >= 0)
    Serial.println("Backlight now on!");
    analogWrite(DISPLAY_BACKLIGHT, BACKLIGHT_MAX);
#endif

    startTime = millis(); // For frame-rate calculation
}

void loop() 
{
    updateEye();
}


/*
* initEye
*
* Initialise eyes
*
*/
static void initEyes(void)
{
    Serial.println("Initialise eye objects");

    // Initialise eye objects based on eyeInfo list in config.h:
    for (uint8_t e = 0; e < NUM_EYES; e++)
    {
        Serial.print("Create display #");
        Serial.println(e);

        eye[e].tft_cs = eyeInfo[e].select;
        eye[e].blink.state = NOBLINK;
        eye[e].xposition = eyeInfo[e].xposition;

        pinMode(eye[e].tft_cs, OUTPUT);
        digitalWrite(eye[e].tft_cs, LOW);

        // Also set up an individual eye-wink pin if defined:
        if (eyeInfo[e].wink >= 0)
            pinMode(eyeInfo[e].wink, INPUT_PULLUP);
    }

#if defined(BLINK_PIN) && (BLINK_PIN >= 0)
    pinMode(BLINK_PIN, INPUT_PULLUP); // Ditto for all-eyes blink pin
#endif
}

/*
* updateEye
*
* Update eyes
*
*/
static void updateEye(void)
{
#if defined(LIGHT_PIN) && (LIGHT_PIN >= 0) // Interactive iris

    int16_t v = analogRead(LIGHT_PIN); // Raw dial/photocell reading
#ifdef LIGHT_PIN_FLIP
    v = 1023 - v; // Reverse reading from sensor
#endif
    if (v < LIGHT_MIN)
        v = LIGHT_MIN; // Clamp light sensor range
    else if (v > LIGHT_MAX)
        v = LIGHT_MAX;
    v -= LIGHT_MIN; // 0 to (LIGHT_MAX - LIGHT_MIN)
#ifdef LIGHT_CURVE  // Apply gamma curve to sensor input?
    v = (int16_t)(pow((double)v / (double)(LIGHT_MAX - LIGHT_MIN),
                      LIGHT_CURVE) *
                  (double)(LIGHT_MAX - LIGHT_MIN));
#endif
    // And scale to iris range (IRIS_MAX is size at LIGHT_MIN)
    v = map(v, 0, (LIGHT_MAX - LIGHT_MIN), IRIS_MAX, IRIS_MIN);
#ifdef IRIS_SMOOTH // Filter input (gradual motion)
    static int16_t irisValue = (IRIS_MIN + IRIS_MAX) / 2;
    irisValue = ((irisValue * 15) + v) / 16;
    frame(irisValue);
#else  // Unfiltered (immediate motion)
    frame(v);
#endif // IRIS_SMOOTH

#else // Autonomous iris scaling -- invoke recursive function

    newIris = (curIrisMin < curIrisMax) ? random(curIrisMin, curIrisMax)
                                        : curIrisMin;
    split(oldIris, newIris, micros(), 10000000L, curIrisMax - curIrisMin);
    oldIris = newIris;

#endif // LIGHT_PIN
}

/*
* drawEye
* 
* Eye rendering function
*
* Inputs:
*  e        Eye array index; 0 or 1 for left/right
*  iScale   Scale factor for iris
*  scleraX  First pixel X offset into sclera image
*  scleraY  First pixel Y offset into sclera image
*  uT       Upper eyelid threshold value
*  lT       Lower eyelid threshold value
*
*/
static void drawEye(uint8_t e, uint32_t iScale, uint32_t scleraX, uint32_t scleraY, uint32_t uT, uint32_t  lT)
{
    uint32_t screenX, screenY, scleraXsave;
    int32_t irisX, irisY;
    uint32_t p, a;
    uint32_t d;

    uint32_t pixels = 0;

    // Set up raw pixel dump to entire screen.  Although such writes can wrap
    // around automatically from end of rect back to beginning, the region is
    // reset on each frame here in case of an SPI glitch.
    digitalWrite(eye[e].tft_cs, LOW);

    tft.startWrite();
    tft.setAddrWindow(eye[e].xposition, 0, SCREEN_HEIGHT, SCREEN_WIDTH);

    // Now just issue raw 16-bit values for every pixel...

    scleraXsave = scleraX; // Save initial X value to reset on each line
    irisY = scleraY - (SCLERA_HEIGHT - IRIS_HEIGHT) / 2;

    // Eyelid image is left<>right swapped for two displays
    uint16_t lidX = 0;
    uint16_t dlidX = -1;

    if (e)
        dlidX = 1;

    for (screenY = 0; screenY < SCREEN_HEIGHT; screenY++, scleraY++, irisY++)
    {
        scleraX = scleraXsave;
        irisX = scleraXsave - (SCLERA_WIDTH - IRIS_WIDTH) / 2;

        if (e)
            lidX = 0;
        else
            lidX = SCREEN_WIDTH - 1;

        for (screenX = 0; screenX < SCREEN_WIDTH; screenX++, scleraX++, irisX++, lidX += dlidX)
        {
            if ((pgm_read_byte(lower + screenY * SCREEN_WIDTH + lidX) <= lT) ||
                (pgm_read_byte(upper + screenY * SCREEN_WIDTH + lidX) <= uT))
            { // Covered by eyelid
                p = 0;
            }
            else if ((irisY < 0) || (irisY >= IRIS_HEIGHT) ||
                     (irisX < 0) || (irisX >= IRIS_WIDTH))
            { // In sclera
                p = pgm_read_word(sclera + scleraY * SCLERA_WIDTH + scleraX);
            }
            else
            {                                                          // Maybe iris...
                p = pgm_read_word(polar + irisY * IRIS_WIDTH + irisX); // Polar angle/dist
                d = (iScale * (p & 0x7F)) / 240;                       // Distance (Y)

                if (d < IRIS_MAP_HEIGHT)
                {                                                     // Within iris area
                    a = (IRIS_MAP_WIDTH * (p >> 7)) / 512;               // Angle (X)
                    p = pgm_read_word(curIris + d * IRIS_MAP_WIDTH + a); // Pixel = iris
                }
                else
                {                                                                 // Not in iris
                    p = pgm_read_word(sclera + scleraY * SCLERA_WIDTH + scleraX); // Pixel = sclera
                }
            }
            *(&pbuffer[dmaBuf][0] + pixels++) = p >> 8 | p << 8;

            if (pixels >= BUFFER_SIZE)
            {
                yield();
#ifdef USE_DMA
                tft.pushPixelsDMA(&pbuffer[dmaBuf][0], pixels);
                dmaBuf = !dmaBuf;
#else
                tft.pushPixels(pbuffer, pixels);
#endif
                pixels = 0;
            }
        }
    }

    if (pixels)
    {
#ifdef USE_DMA
        tft.pushPixelsDMA(&pbuffer[dmaBuf][0], pixels);
#else
        tft.pushPixels(pbuffer, pixels);
#endif
    }
    tft.endWrite();
    digitalWrite(eye[e].tft_cs, HIGH);
}

// EYE ANIMATION -----------------------------------------------------------

// Ease in/out curve for eye movements 3*t^2-2*t^3
const uint8_t ease[] = { 
  0,  0,  0,  0,  0,  0,  0,  1,  1,  1,  1,  1,  2,  2,  2,  3,                    // T
  3,  3,  4,  4,  4,  5,  5,  6,  6,  7,  7,  8,  9,  9, 10, 10,                    // h
  11, 12, 12, 13, 14, 15, 15, 16, 17, 18, 18, 19, 20, 21, 22, 23,                   // x
  24, 25, 26, 27, 27, 28, 29, 30, 31, 33, 34, 35, 36, 37, 38, 39,                   // 2
  40, 41, 42, 44, 45, 46, 47, 48, 50, 51, 52, 53, 54, 56, 57, 58,                   // A
  60, 61, 62, 63, 65, 66, 67, 69, 70, 72, 73, 74, 76, 77, 78, 80,                   // l
  81, 83, 84, 85, 87, 88, 90, 91, 93, 94, 96, 97, 98, 100, 101, 103,                // e
  104, 106, 107, 109, 110, 112, 113, 115, 116, 118, 119, 121, 122, 124, 125, 127,   // c
  128, 130, 131, 133, 134, 136, 137, 139, 140, 142, 143, 145, 146, 148, 149, 151,   // J
  152, 154, 155, 157, 158, 159, 161, 162, 164, 165, 167, 168, 170, 171, 172, 174,   // a
  175, 177, 178, 179, 181, 182, 183, 185, 186, 188, 189, 190, 192, 193, 194, 195,   // c
  197, 198, 199, 201, 202, 203, 204, 205, 207, 208, 209, 210, 211, 213, 214, 215,   // o
  216, 217, 218, 219, 220, 221, 222, 224, 225, 226, 227, 228, 228, 229, 230, 231,   // b
  232, 233, 234, 235, 236, 237, 237, 238, 239, 240, 240, 241, 242, 243, 243, 244,   // s
  245, 245, 246, 246, 247, 248, 248, 249, 249, 250, 250, 251, 251, 251, 252, 252,   // o
  252, 253, 253, 253, 254, 254, 254, 254, 254, 255, 255, 255, 255, 255, 255, 255    // n
};

#ifdef AUTOBLINK
uint32_t timeOfLastBlink = 0L, timeToNextBlink = 0L;
#endif

/*
* frame
*
* Process motion for a single frame of left or right eye
*
* Inputs:
*  iScale   Iris scale (0-1023)
*
*/
static void frame(uint16_t iScale)
{
    static uint32_t frames = 0;  // Used in frame rate calculation
    static uint8_t eyeIndex = 0; // eye[] array counter
    int16_t eyeX, eyeY;
    uint32_t t = micros(); // Time at start of function

    checkIrisButton(); // Nut doi loi mat

    // Loi mat "phang" (Sharingan): iScale co dinh, bo qua gia tri tu split()
    if (curIrisMin == curIrisMax)
    {
        iScale = curIrisMin;
    }

    if (!(++frames & 255))
    { // Every 256 frames...
        float elapsed = (millis() - startTime) / 1000.0;

        if (elapsed)
        {
            Serial.println((uint16_t)(frames / elapsed)); // Print FPS
        }
    }

    if (++eyeIndex >= NUM_EYES)
    {
        eyeIndex = 0; // Cycle through eyes, 1 per call
    }
        // X/Y movement

#if defined(JOYSTICK_X_PIN) && (JOYSTICK_X_PIN >= 0) && \
    defined(JOYSTICK_Y_PIN) && (JOYSTICK_Y_PIN >= 0)

    // Read X/Y from joystick, constrain to circle
    int16_t dx, dy;
    int32_t d;

    eyeX = analogRead(JOYSTICK_X_PIN); // Raw (unclipped) X/Y reading
    eyeY = analogRead(JOYSTICK_Y_PIN);
#ifdef JOYSTICK_X_FLIP
    eyeX = 1023 - eyeX;
#endif
#ifdef JOYSTICK_Y_FLIP
    eyeY = 1023 - eyeY;
#endif
    dx = (eyeX * 2) - 1023; // A/D exact center is at 511.5.  Scale coords
    dy = (eyeY * 2) - 1023; // X2 so range is -1023 to +1023 w/center at 0.

    if ((d = (dx * dx + dy * dy)) > (1023 * 1023))
    {                                        // Outside circle
        d = (int32_t)sqrt((float)d);         // Distance from center
        eyeX = ((dx * 1023 / d) + 1023) / 2; // Clip to circle edge,
        eyeY = ((dy * 1023 / d) + 1023) / 2; // scale back to 0-1023
    }

#else  // Autonomous X/Y eye motion
    // Periodically initiates motion to a new random point, random speed,
    // holds there for random period until next motion.

    static bool eyeInMotion = false;
    static int16_t eyeOldX = 512, eyeOldY = 512, eyeNewX = 512, eyeNewY = 512;
    static uint32_t eyeMoveStartTime = 0L;
    static int32_t eyeMoveDuration = 0L;

    int32_t dt = t - eyeMoveStartTime; // uS elapsed since last eye event

    if (eyeInMotion)
    { // Currently moving?
        if (dt >= eyeMoveDuration)
        {                                      // Time up?  Destination reached.
            eyeInMotion = false;               // Stop moving
            eyeMoveDuration = random(3000000); // 0-3 sec stop
            eyeMoveStartTime = t;              // Save initial time of stop
            eyeX = eyeOldX = eyeNewX;          // Save position
            eyeY = eyeOldY = eyeNewY;
        }
        else
        {                                                       // Move time's not yet fully elapsed -- interpolate position
            int16_t e = ease[255 * dt / eyeMoveDuration] + 1;   // Ease curve

            eyeX = eyeOldX + (((eyeNewX - eyeOldX) * e) / 256); // Interp X
            eyeY = eyeOldY + (((eyeNewY - eyeOldY) * e) / 256); // and Y
        }
    }
    else
    { // Eye stopped
        eyeX = eyeOldX;
        eyeY = eyeOldY;

        if (dt > eyeMoveDuration)
        { // Time up?  Begin new move.
            int16_t dx, dy;
            uint32_t d;

            do
            { // Pick new dest in circle
                eyeNewX = random(1024);
                eyeNewY = random(1024);
                dx = (eyeNewX * 2) - 1023;
                dy = (eyeNewY * 2) - 1023;
            } while ((d = (dx * dx + dy * dy)) > (1023 * 1023)); // Keep trying

            eyeMoveDuration = random(72000, 144000);             // ~1/14 - ~1/7 sec
            eyeMoveStartTime = t;                                // Save initial time of move
            eyeInMotion = true;                                  // Start move on next frame
        }
    }
#endif // JOYSTICK_X_PIN etc.

    // Blinking
#ifdef AUTOBLINK
    // Similar to the autonomous eye movement above -- blink start times
    // and durations are random (within ranges).
    if ((t - timeOfLastBlink) >= timeToNextBlink)
    { // Start new blink?
        timeOfLastBlink = t;
        uint32_t blinkDuration = random(36000, 72000); // ~1/28 - ~1/14 sec

        // Set up durations for both eyes (if not already winking)
        for (uint8_t e = 0; e < NUM_EYES; e++)
        {
            if (eye[e].blink.state == NOBLINK)
            {
                eye[e].blink.state = ENBLINK;
                eye[e].blink.startTime = t;
                eye[e].blink.duration = blinkDuration;
            }
        }
        timeToNextBlink = blinkDuration * 3 + random(4000000);
    }
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

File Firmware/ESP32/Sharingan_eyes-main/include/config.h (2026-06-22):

#ifndef __CONFIG__
#define __CONFIG__

// Pin selections here are based on the original Adafruit Learning System
// guide for the Teensy 3.x project.  Some of these pin numbers don't even
// exist on the smaller SAMD M0 & M4 boards, so you may need to make other
// selections:

// GRAPHICS SETTINGS (appearance of eye) -----------------------------------

// If using a SINGLE EYE, you might want this next line enabled, which
// uses a simpler "football-shaped" eye that's left/right symmetrical.
// Default shape includes the caruncle, creating distinct left/right eyes.

// #define SYMMETRICAL_EYELID

// Enable ONE of these #includes -- HUGE graphics tables for various eyes:
#include "eyes/defaultEye.h"    // Standard human-ish hazel eye -OR-
                                // More to comme

// Cac loi mat (iris) bo sung, doi luc chay bang nut bam:
#include "eyes/iris_tomoe.h"    // Sharingan tomoe
#include "eyes/iris_kamui.h"    // Mangekyou Kamui (Obito)
#include "eyes/iris_sasuke.h"   // Mangekyou vinh hang (Sasuke)
#include "eyes/iris_rinnegan.h" // Rinnegan

#define IRIS_SWITCH_PIN 27      // Nut bam doi loi mat (noi GND, INPUT_PULLUP)

// DISPLAY HARDWARE SETTINGS (screen type & connections) -------------------
#define TFT_COUNT 2        // Number of screens (1 or 2)
#define TFT1_CS 5          // TFT 1 chip select pin (set to -1 to use TFT_eSPI setup)
#define TFT2_CS 21         // TFT 2 chip select pin (set to -1 to use TFT_eSPI setup)
#define TFT_1_ROT 0        // TFT 1 rotation
#define TFT_2_ROT 0        // TFT 2 rotation
#define EYE_1_XPOSITION  0  // x shift for eye 1 image on display
#define EYE_2_XPOSITION  0  // x shift for eye 2 image on display

#define DISPLAY_SIZE 240

#define DISPLAY_BACKLIGHT  -1 // Pin for backlight control (-1 for none); BLK wired to 3V3
#define BACKLIGHT_MAX      128

// EYE LIST ----------------------------------------------------------------
#define NUM_EYES 2 // Number of eyes to display (1 or 2)

#define BLINK_PIN   -1 // Pin for manual blink button (BOTH eyes)
#define LH_WINK_PIN -1 // Left wink pin (set to -1 for no pin)
#define RH_WINK_PIN -1 // Right wink pin (set to -1 for no pin)

// INPUT SETTINGS (for controlling eye motion) -----------------------------
// JOYSTICK_X_PIN and JOYSTICK_Y_PIN specify analog input pins for manually
// controlling the eye with an analog joystick.  If set to -1 or if not
// defined, the eye will move on its own.
// IRIS_PIN speficies an analog input pin for a photocell to make pupils
// react to light (or potentiometer for manual control).  If set to -1 or
// if not defined, the pupils will change on their own.
// BLINK_PIN specifies an input pin for a button (to ground) that will
// make any/all eyes blink.  If set to -1 or if not defined, the eyes will
// only blink if AUTOBLINK is defined, or if the eyeInfo[] table above
// includes wink button settings for each eye.

//#define JOYSTICK_X_PIN A0 // Analog pin for eye horiz pos (else auto)
//#define JOYSTICK_Y_PIN A1 // Analog pin for eye vert position (")
//#define JOYSTICK_X_FLIP   // If defined, reverse stick X axis
//#define JOYSTICK_Y_FLIP   // If defined, reverse stick Y axis
#define TRACKING            // If defined, eyelid tracks pupil
#define AUTOBLINK           // If defined, eyes also blink autonomously

//  #define LIGHT_PIN      -1 // Light sensor pin
  #define LIGHT_CURVE  0.33 // Light sensor adjustment curve
  #define LIGHT_MIN       0 // Minimum useful reading from light sensor
  #define LIGHT_MAX    1023 // Maximum useful reading from sensor

#define IRIS_SMOOTH         // If enabled, filter input from IRIS_PIN
#if !defined(IRIS_MIN)      // Each eye might have its own MIN/MAX
  #define IRIS_MIN       90 // Iris size (0-1023) in brightest light
#endif
#if !defined(IRIS_MAX)
  #define IRIS_MAX      130 // Iris size (0-1023) in darkest light
#endif

#endif
